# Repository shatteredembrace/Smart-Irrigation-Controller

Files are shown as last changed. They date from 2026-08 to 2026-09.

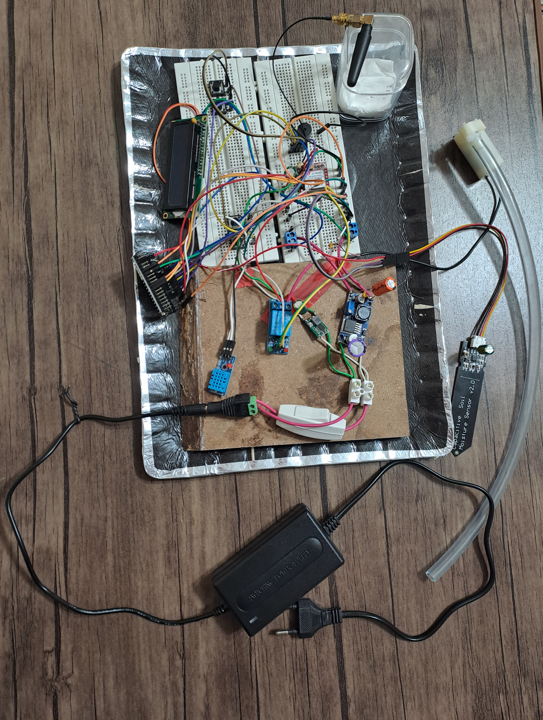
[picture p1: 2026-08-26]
Prototype/img/20260826_171202.jpg

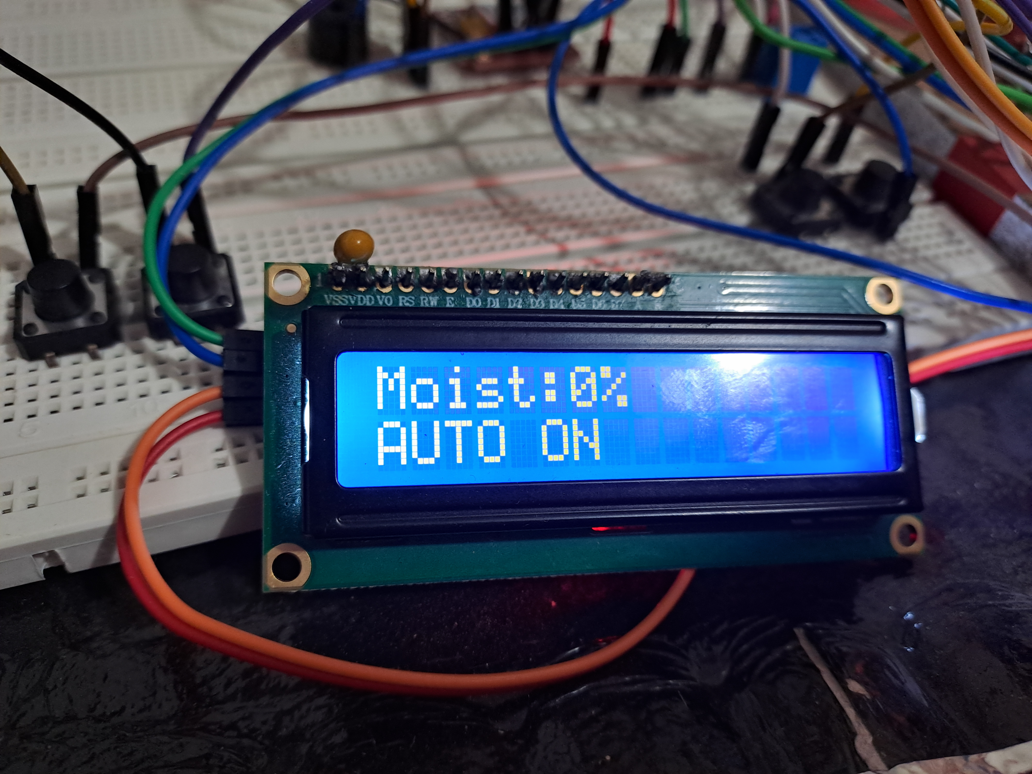
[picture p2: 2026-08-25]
Prototype/img/20260826_011637.jpg

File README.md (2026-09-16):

# Smart Irrigation Controller(Work in progress)

ESP32-based smart irrigation controller with automatic soil-moisture control, GSM communication, Wi-Fi API, environmental monitoring, and safety protection.

> **License:** Proprietary — All Rights Reserved. Contributions are welcome via Pull Requests. See [LICENSE](LICENSE) and [CONTRIBUTING.md](CONTRIBUTING.md) for details.

## Project Status
- [x] KiCad schematic
- [x] ERC verification
- [x] Prototype firmware
- [ ] PCB design
- [ ] PCB fabrication
- [ ] Final hardware testing

## Main Features

- Automatic irrigation based on soil moisture
- Manual pump control
- ESP32 control system
- Soil-moisture sensing
- DHT11 temperature and humidity monitoring
- SIM800L GSM/SMS communication
- Wi-Fi connectivity and HTTP API
- LCD user interface
- Push-button menu system
- EEPROM configuration storage
- Pump runtime protection
- Sensor fault detection
- GSM alert system

## Hardware

The current hardware design includes:

- ESP32 38-pin module
- LM2596 voltage regulator
- Mini360 voltage regulator
- SIM800L
- DHT11
- Soil-moisture sensor
- Relay driver
- 2N2222 transistor
- LCD with I2C interface
- Push buttons
- Buzzer
- 12 V power input
- General-purpose electrolytic capacitors(1000uF)
- Low-ESR capacitors(1000uF)
- Ceramic capacitors(100nF)

## Repository Structure

```

├── README.md
├── LICENSE
├── firmware/
├── hardware/
│   ├── schematic/
│   └── documentation/
├── docs/
│   ├── hardware-design.md
│   ├── firmware-architecture.md
│   ├── troubleshooting.md
│   ├── testing.md
│   └── communication.md
└── prototype/
```

Schematic

The current KiCad schematic represents the electrical architecture of the prototype.

PCB design will be developed in a later revision.

## Future Work :

PCB layout
PCB fabrication
Hardware validation
Final enclosure
Improved power protection
Extended communication features

## Overview

This project is an ESP32-based smart irrigation controller designed to monitor soil moisture and control a water pump according to configurable moisture thresholds. The system supports both automatic and manual operation through a local LCD interface, while also providing remote control and status monitoring through Wi-Fi and GSM/SMS communication.
The controller uses a soil-moisture sensor as the primary input for automatic irrigation, with a DHT sensor providing environmental temperature and humidity data. A relay-driven pump provides the irrigation output, while configurable calibration values and start/stop thresholds allow the system to be adapted to different soil and sensor characteristics.
The hardware was developed and validated initially as a functional prototype. The current repository documents the validated schematic and firmware; PCB design and further hardware refinement are planned as subsequent development stages.

## Features

•	Automatic irrigation based on configurable soil-moisture start and stop thresholds.

•	Manual pump control through the local LCD interface.

•	Soil-moisture calibration using configurable dry and wet reference values.

•	Temperature and humidity monitoring using a DHT sensor.

•	LCD user interface with dashboard, operating-mode selection, manual pump control, and configuration menus.

•	Wi-Fi connectivity for remote status monitoring and authenticated pump/control commands through an HTTP API.

•	GSM/SMS connectivity through the SIM800L module for remote commands and status communication.

•	Relay-based pump control with software handling of the relay's active logic.

•	Pump runtime protection to prevent the pump from operating continuously beyond the configured safety limit.

•	Sensor fault detection with pump shutdown when a critical soil-moisture sensor fault is detected.

•	Persistent configuration for operating mode, moisture thresholds, and calibration parameters.

•	Audible feedback through a buzzer for user-interface actions and system events.

## System Architecture

The system is organized around an ESP32 microcontroller that acts as the central control and communication unit. It acquires sensor data, manages the irrigation state, drives the pump relay, updates the local LCD interface, and handles remote commands received through Wi-Fi and GSM.

Functional Architecture
```

                         ┌─────────────────────┐
                         │       ESP32         │
                         │                     │
                         │  Control Logic      │
                         │  State Management   │
                         │  UI Management      │
                         │  Communications     │
                         └──────────┬──────────┘
                                    │
          ┌─────────────────────────┼─────────────────────────┐
          │                         │                         │
          ▼                         ▼                         ▼
   ┌─────────────┐           ┌─────────────┐           ┌─────────────┐
   │ Soil Sensor │           │ DHT Sensor  │           │ LCD + I²C   │
   │  Moisture   │           │ Temp/Humid. │           │    UI       │
   └─────────────┘           └─────────────┘           └─────────────┘
          │
          │ moisture data
          ▼
   ┌─────────────────────────────────────────────────────────────┐
   │                    Irrigation Control                       │
   │                                                             │
   │   AUTO:   START/STOP thresholds determine pump state        │
   │   MANUAL: User directly controls pump state                 │
   └──────────────────────────────┬──────────────────────────────┘
                                  │
                                  ▼
                           ┌─────────────┐
                           │ Relay Driver│
                           │  2N2222     │
                           └──────┬──────┘
                                  │
                                  ▼
                           ┌─────────────┐
                           │    Relay    │
                           └──────┬──────┘
                                  │
                                  ▼
                              ┌───────┐
                              │ Pump  │
                              └───────┘

        ┌─────────────────┐                 ┌─────────────────┐
        │      Wi-Fi      │                 │     SIM800L     │
        │  HTTP API       │                 │    GSM / SMS    │
        └────────┬────────┘                 └────────┬────────┘
                 │                                   │
                 └────────────────┬──────────────────┘
                                  ▼
                               ESP32
```

The separate regulator paths isolate the high-current GSM load from the main logic supply while maintaining a common electrical reference between the subsystems. The common ground is required for reliable signal communication between the ESP32 and externally powered modules such as the SIM800L.

## Hardware Design

### Main Controller
ESP32 acts as the central controller, handling sensor acquisition,
irrigation control, user interface, and communication.

### Power Supply
The system uses a 12 V input with separate regulated supply paths
for the ESP32/logic and SIM800L. The separate branches reduce the
effect of GSM transient current demand on the main logic supply,
while maintaining a common ground reference.

### Sensors
- Capacitive soil-moisture sensor connected to an ESP32 ADC input.
- DHT sensor for temperature and relative humidity.

### Pump Control
The pump is switched through a relay driven by a 2N2222 transistor,
rather than directly from an ESP32 GPIO.

### User Interface
A 16×2 I²C LCD and physical buttons provide local monitoring,
configuration, and manual pump control.

### Communication
- Wi-Fi through the ESP32's integrated interface and HTTP API.
- GSM/SMS through the SIM800L UART interface.

### Power Integrity
Local decoupling and bulk capacitance are used to support supply
stability and transient load behavior.

## Design Philosophy

The hardware was designed around several principles:

1.	Keep high-current loads away from direct microcontroller GPIO drive.
2.	Provide appropriate regulation for subsystems with different power requirements.
3.	Maintain a common signal reference between communicating subsystems.
4.	Use calibration rather than assuming a universal raw sensor-to-percentage relationship.
5.	Keep the schematic readable through functional grouping and appropriate net labeling.
6.	Treat power integrity and transient behavior as part of the system design rather than as an afterthought.

## Firmware Architecture

The firmware is organized around a non-blocking control loop in which sensor acquisition, user-interface handling, irrigation control, communication, and safety checks are processed as independent tasks.
The ESP32 acts as the central software controller and maintains the current system state, including the operating mode, sensor measurements, pump state, configuration parameters, and communication status.

Main Control Flow
```

                    ┌──────────────────┐
                    │   System Setup   │
                    │                  │
                    │ GPIO / LCD /     │
                    │ Sensors / Wi-Fi  │
                    │ GSM initialization│
                    └────────┬─────────┘
                             │
                             ▼
                    ┌──────────────────┐
                    │    Main Loop     │
                    └────────┬─────────┘
                             │
          ┌──────────────────┼───────────────────┐
          │                  │                   │
          ▼                  ▼                   ▼
   Sensor Processing    User Interface      Communications
          │                  │                   │
          ▼                  ▼                   ▼
   Sensor / Fault       LCD + Buttons       Wi-Fi + GSM
      State                  │                   │
          │                  └────────┬──────────┘
          │                           │
          └──────────────┬────────────┘
                         ▼
                 Irrigation Control
                         │
              ┌──────────┴──────────┐
              │                     │
             AUTO                 MANUAL
              │                     │
        START / STOP            User command
        thresholds                  │
              │                     │
              └──────────┬──────────┘
                         ▼
                    Pump Control
                         │
                         ▼
                       Relay
```

## Operating Modes

The firmware maintains two primary irrigation modes.

AUTO Mode:
In automatic mode, the pump state is determined from the calibrated soil-moisture measurement and the configured START and STOP thresholds.
The use of separate start and stop thresholds provides hysteresis. This prevents the pump from rapidly switching states when the measured moisture is close to a single threshold.
Conceptually:
Moisture < START  → Pump ON
Moisture ≥ STOP   → Pump OFF
The exact boundary behavior is implemented by the firmware.
MANUAL Mode:
In manual mode, the automatic moisture-control decision is disabled and the user directly selects the pump state through the LCD interface.
The manual interface provides explicit PUMP ON and PUMP OFF commands.
This separates user-directed operation from the automatic irrigation algorithm.

## Control Logic

The soil-moisture sensor is sampled through the ESP32 ADC and
converted to a normalized moisture percentage using configurable
DRY and WET calibration references.

All pump-control paths converge on the same control mechanism:

- Automatic moisture control
- LCD manual control
- Wi-Fi commands
- GSM/SMS commands

A configurable pump-runtime timeout provides an additional safeguard
against indefinite pump operation.

## LCD User Interface
```
The LCD interface is implemented as a collection of screens/states rather than as one continuously redrawn menu.
The main interface consists of:
Main Menu
├── AUTO
├── MANUAL
│   ├── PUMP ON
│   └── PUMP OFF
└── SETTINGS
    ├── START
    ├── STOP
    ├── DRY
    └── WET
The settings interface allows the user to modify the automatic irrigation thresholds and sensor calibration parameters.
The display logic also explicitly manages the contents of individual LCD fields so that remnants of previous, longer strings are not left visible after navigation.
```

## Communication Interfaces

### Wi-Fi

The ESP32 exposes an HTTP API for status monitoring and authenticated
control commands.

GET /status

/control?key=<API_KEY>&cmd=<COMMAND>

Supported commands include:

- AUTO
- MANUAL
- PUMP_ON
- PUMP_OFF
- RESET_PUMP

### GSM / SMS

The SIM800L provides an independent remote-control path through SMS.
Received commands are routed through the same command-processing layer
used by the local and Wi-Fi interfaces.

## Configuration and Persistence

User-configurable parameters are stored separately from transient runtime state.
Configuration includes the values required for irrigation thresholds and sensor calibration. 

## Safety and Fault Handling

The firmware includes software-level safeguards intended to prevent
common sensor and control failures from causing uncontrolled pump
operation.

Implemented protections include:

- Critical soil-moisture sensor fault handling
- Maximum continuous pump runtime
- Pump-state validation
- Hysteresis between START and STOP thresholds
- Consistent command routing across local and remote interfaces

The general failure-handling principle is to prevent unreliable
conditions from resulting in indefinite irrigation.

## Troubleshooting & Engineering Validation

Prototype debugging was performed using a measurement-based fault
isolation approach rather than modifying firmware based only on
observed symptoms.

The development process included:

- Schematic inspection
- Continuity and voltage measurements
- Serial diagnostics
- Subsystem isolation
- Controlled functional tests
- KiCad ERC validation

Representative issues included:

- SIM800L UART failure caused by missing common ground between
  independently regulated subsystems.
- Relay/pump logic inversion caused by the relay's active-low interface.
- LCD residual characters caused by rewriting shorter strings over
  longer previous content.
- DHT communication failures investigated independently from other
  subsystems.
- KiCad ERC errors resolved by correcting actual connectivity and
  electrical-type issues rather than broadly suppressing checks.

## Testing & Validation
```

The prototype was tested incrementally, with individual subsystems validated before being tested as an integrated system. Functional tests were performed on the sensor interfaces, user interface, actuator control, Wi-Fi API, and GSM communication.
Functional Test Matrix
Subsystem	Test	Expected Result	Result
ESP32	Power-up and initialization	Controller starts normally	✅
Soil sensor	Change sensor conditions	Moisture reading changes accordingly	✅
DHT sensor	Read temperature and humidity	Valid environmental readings are obtained	✅
LCD	Dashboard display	Current system state is displayed correctly	✅
LCD	Menu navigation	Menus can be navigated using the buttons	✅
LCD	Manual pump control	User can turn the pump ON/OFF	✅
LCD	Configuration	START/STOP and calibration values can be modified	✅
Relay	Pump ON command	Relay switches to the active state	✅
Pump	Manual ON/OFF	Physical pump follows the selected state	✅
AUTO mode	Low moisture condition	Pump activates according to START threshold	✅
AUTO mode	Adequate moisture condition	Pump stops according to STOP threshold	✅
Pump safety	Extended continuous operation	Safety timeout prevents indefinite operation	✅
Wi-Fi	Network connection	ESP32 connects and obtains an IP address	✅
HTTP API	/status	Valid JSON system status is returned	✅
HTTP API	Unauthorized control request	Request is rejected	✅
HTTP API	Authenticated MANUAL command	Command is accepted	✅
HTTP API	Authenticated PUMP_ON	Pump activates	✅
HTTP API	Authenticated PUMP_OFF	Pump stops	✅
SIM800L	AT communication	Modem responds to initialization commands	✅
GSM/SMS	SMS reception	Incoming command is detected and parsed	✅
GSM/SMS	STATUS	Status response is returned by SMS	✅
GSM/SMS	Pump control	SMS command changes pump state	✅
Schematic	KiCad ERC	No unresolved ERC errors remain	✅
```

## Build and Setup

### Hardware

Before powering the prototype, verify:

- Input supply voltage
- Regulated supply voltages
- Common ground connections
- ESP32 GPIO assignments
- Sensor connections
- Relay and pump connections
- SIM800L power and UART connections

Refer to the KiCad schematic and pin-assignment documentation for
the complete electrical connections.

### Firmware

The firmware is developed for the ESP32 using the Arduino framework.

Before compiling, configure the project-specific parameters:

- Wi-Fi credentials
- Wi-Fi API key
- GSM/SIM configuration
- Hardware pin assignments
- Irrigation defaults

Real credentials must never be committed to the public repository.

### Initial Configuration

1. Verify sensor readings.
2. Perform DRY/WET calibration.
3. Configure START/STOP thresholds.
4. Verify manual pump operation.
5. Test AUTO mode.
6. Test Wi-Fi/API control.
7. Test GSM/SMS functionality.
8. Verify pump safety behavior.

## Security

The public repository must not contain real:
•	Wi-Fi passwords;
•	API keys;
•	SIM credentials;
•	telephone numbers;
•	other authentication secrets.
Example placeholders should be used instead:
WIFI_SSID     = "YOUR_WIFI_SSID"
WIFI_PASSWORD = "YOUR_WIFI_PASSWORD"
WIFI_API_KEY  = "YOUR_API_KEY"
The API key should be treated as a credential even though the project is intended as a prototype.

## User Guide

For detailed operating instructions, see
[User Guide](docs/user-guide.md).

##Security Considerations

The Wi-Fi control endpoint is protected by an API key.
The API key must be treated as a credential and must not be committed to the public repository.

## Future Work

### PCB Development

Replace prototype wiring with a dedicated PCB featuring controlled
routing, dedicated connectors, improved power distribution, and
better mechanical integration.

### Power Integrity

Further validate supply stability during worst-case GSM transmission
bursts and simultaneous pump operation.

### Electrical Protection

Add production-oriented protection such as:

- Overvoltage protection
- Reverse-polarity protection
- Fusing
- Transient suppression
- Improved actuator isolation
- Hardware-level pump shutdown

### Environmental & Mechanical Design

Develop a suitable enclosure with appropriate ingress protection,
connector protection, cable strain relief, thermal management,
mounting, and serviceability.

### Sensor Calibration

Improve the calibration workflow and evaluate long-term effects of
sensor aging, soil composition, environmental conditions, and
installation depth.

### Communication Security

Replace the prototype-oriented API-key security model with stronger
authentication, encrypted transport, credential management, and
network isolation where required.

### Reliability Testing

Perform long-duration testing, repeated switching, power-cycle tests,
sensor-disconnection tests, communication-loss tests, and
brownout/transient-condition testing.

### Firmware

Potential improvements include OTA updates, enhanced diagnostics,
event logging, fault recovery, and expanded configuration management.

## Current Scope
```
The current project should therefore be considered a functional embedded-systems prototype, rather than a finished commercial irrigation product.
The current revision demonstrates the integration of:
Sensors
   ↓
ESP32 control system
   ↓
Local user interface
   ↓
Automatic / manual control
   ↓
Relay / pump actuator

          +
Wi-Fi remote control
          +
GSM / SMS communication
          +
```

Software safety mechanisms

PCB development, production-level protection, environmental packaging, extensive reliability testing, and production-grade communication security constitute subsequent engineering stages.

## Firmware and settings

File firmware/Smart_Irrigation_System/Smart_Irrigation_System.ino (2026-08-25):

#include <EEPROM.h>
#include <Wire.h>
#include <LiquidCrystal_I2C.h>
#include <DHT.h>
#include <HardwareSerial.h>
#include <WiFi.h>
#include <WebServer.h>
#include <esp_task_wdt.h>

LiquidCrystal_I2C lcd(0x27, 16, 2);

// ==========================================
// 1 & 2: Constexpr Definitions (Modern C++)
// ==========================================
constexpr uint16_t EEPROM_SIZE = 128;
constexpr uint16_t SETTINGS_ADDR = 0;

constexpr uint16_t EEPROM_MAGIC_VAL = 0xA55A;
constexpr uint8_t  EEPROM_VERSION_VAL = 1;

constexpr uint8_t SOIL_PIN   = 34;
constexpr uint8_t RELAY_PIN  = 27;
constexpr uint8_t UP_BTN     = 32;
constexpr uint8_t DOWN_BTN   = 33;
constexpr uint8_t ENTER_BTN  = 25;
constexpr uint8_t BACK_BTN   = 26;
constexpr uint8_t BUZZER_PIN = 14;

// DHT Settings
constexpr uint8_t DHT_PIN = 13;
constexpr uint8_t DHT_TYPE = DHT11;

// SIM800L Settings
constexpr char ALERT_PHONE[] = "+XXXXXXXXXX";
constexpr uint8_t AUTHORIZED_NUMBERS = 2; //it can be more

const char* authorizedNumbers[AUTHORIZED_NUMBERS] =
{
  "+xxxxxxxxxxxx",
  "+yyyyyyyyyyyy"
};

constexpr uint8_t SIM800_RX_PIN = 16;
constexpr uint8_t SIM800_TX_PIN = 17;
constexpr uint32_t SIM800_BAUD = 9600;

// Wi-Fi Settings
constexpr char WIFI_SSID[] = "YOUR WIFI_NAME";
constexpr char WIFI_PASSWORD[] = "YOUR PASSWORD";
constexpr char WIFI_API_KEY[] = "YOUR API_KEY";


constexpr bool RELAY_ON  = LOW;
constexpr bool RELAY_OFF = HIGH;

// Menu Bounds
constexpr uint8_t MAIN_MENU_ITEMS = 3;
constexpr uint8_t SETTINGS_MENU_ITEMS = 4;

// Default Configuration Values
constexpr uint8_t DEFAULT_START = 35;
constexpr uint8_t DEFAULT_STOP  = 60;
constexpr uint16_t DEFAULT_DRY  = 2800;
constexpr uint16_t DEFAULT_WET  = 1800;

// ==========================================
// 3: System Constants
// ==========================================
constexpr uint32_t GSM_INIT_RETRY_DELAY = 3000;
constexpr uint32_t WDT_TIMEOUT_SECONDS = 30;
constexpr uint32_t EEPROM_RETRY_DELAY = 1000;
constexpr uint8_t EEPROM_MAX_RETRIES = 3;
constexpr uint32_t PUMP_FAULT_RESET_HOLD = 3000;
constexpr const char* CMD_RESET_PUMP = "RESET PUMP";
constexpr uint16_t CAL_MIN_DIFF = 300;
constexpr uint8_t DHT_FAIL_LIMIT = 3;
constexpr uint8_t DHT_RECOVERY_LIMIT = 2;
constexpr uint8_t SENSOR_BAD_SAMPLE_LIMIT = 5;
constexpr uint8_t SENSOR_GOOD_SAMPLE_LIMIT = 10;
constexpr uint8_t ALERT_QUEUE_SIZE = 8;
constexpr uint8_t ALERT_MESSAGE_SIZE = 96;

constexpr uint32_t GSM_NETWORK_CHECK_INTERVAL = 10000;
constexpr uint32_t GSM_SIGNAL_CHECK_INTERVAL  = 30000;
constexpr uint32_t GSM_RECOVERY_DELAY         = 30000;

constexpr uint8_t GSM_MAX_NETWORK_FAILURES = 3;
constexpr uint8_t GSM_MAX_MODEM_FAILURES   = 3;
constexpr uint32_t LCD_REFRESH_TIME    = 250;
constexpr uint32_t SERIAL_REFRESH_TIME = 1000;
constexpr uint32_t BUTTON_DEBOUNCE     = 50; 
constexpr uint32_t EEPROM_COMMIT_DELAY = 5000;
constexpr uint32_t MAX_PUMP_RUNTIME    = 900000; // 15 Minutes
constexpr uint32_t DHT_INTERVAL        = 2000; 

// ==========================================
// Hardware Objects
// ==========================================
DHT dht(DHT_PIN, DHT_TYPE);
HardwareSerial sim800(2);

// ==========================================
// 4: Enum Classes
// ==========================================
enum class Mode : uint8_t
{
  AUTO,
  MANUAL
};

enum class Screen : uint8_t
{
  DASHBOARD,
  MAIN_MENU,
  SETTINGS_MENU,
  MANUAL_MENU,
  EDIT_START,
  EDIT_STOP,
  EDIT_DRY,
  EDIT_WET
};

// ==========================================
// 5 & 6: Struct & Memory Layout Validation
// ==========================================
struct DeviceSettings
{
  uint16_t magic;
  uint8_t  version;
  Mode     mode;
  uint8_t  startMoisture;
  uint8_t  stopMoisture;
  uint16_t dryValue;
  uint16_t wetValue;
};

static_assert(sizeof(DeviceSettings) <= 16, "DeviceSettings grew unexpectedly.");

DeviceSettings settings;

// Forward Declarations
void changeMode(Mode mode);
int getMoisture();

bool isCalibrationValid(
  uint16_t dryValue,
  uint16_t wetValue
);

// ==========================================
// 7: Hardware Abstraction (Input & Sensors)
// ==========================================
struct Button {
  uint8_t pin;
  bool state = HIGH;
  bool lastFlicker = HIGH;
  bool lastState = HIGH;
  unsigned long lastDebounceTime = 0;

  void init(uint8_t p) {
    pin = p;
    pinMode(pin, INPUT_PULLUP);
  }

  void update() {
    lastState = state; 
    bool reading = digitalRead(pin);

    if (reading != lastFlicker) {
      lastDebounceTime = millis();
    }

    if ((millis() - lastDebounceTime) > BUTTON_DEBOUNCE) {
      if (reading != state) {
        state = reading;
      }
    }
    lastFlicker = reading;
  }

  bool isPressed() const {
    return (lastState == HIGH && state == LOW);
  }
};

Button btnUp, btnDown, btnEnter, btnBack;

struct DHTData
{
  float temperature = 0.0f;
  float humidity = 0.0f;

  bool valid = false;

  uint8_t failCount = 0;
  uint8_t successCount = 0;

  unsigned long lastRead = 0;
};

DHTData dhtData;

// ==========================================
// 8: Error Manager
// ==========================================
struct ErrorManager
{
  bool sensorFault = false;
  bool pumpTimeout = false;
  bool calibrationError = false;
  bool eepromError = false;

  uint8_t sensorBadSamples = 0;
  uint8_t sensorGoodSamples = 0;
};
ErrorManager systemError;

// ==========================================
// Communication Subsystems (GSM & Wi-Fi)
// ==========================================
struct GSMManager
{
  bool initialized = false;
  bool networkRegistered = false;
  bool smsReady = false;

  int signalStrength = -1;

  uint8_t networkFailCount = 0;
  uint8_t modemFailCount = 0;

  unsigned long lastNetworkCheck = 0;
  unsigned long lastSignalCheck = 0;
  unsigned long lastRecoveryAttempt = 0;

  bool pumpTimeoutAlertSent = false;
  bool sensorFaultAlertSent = false;
};

GSMManager gsm;

enum class GSMState : uint8_t
{
  OFFLINE,
  INITIALIZING,
  ONLINE,
  DEGRADED,
  RECOVERING
};

enum class GSMInitStep : uint8_t
{
  NONE,
  AT,
  ECHO_OFF,
  SIM_CHECK,
  SMS_MODE,
  CHARSET,
  SMS_NOTIFICATION,
  COMPLETE,
  FAILED
};

enum class CommandType : uint8_t
{
  NONE,
  PUMP_ON,
  PUMP_OFF,
  MODE_AUTO,
  MODE_MANUAL,
  RESET_PUMP_FAULT,
  GET_STATUS
};
enum class CommandResult : uint8_t
{
  SUCCESS,
  REJECTED,
  INVALID,
  SAFETY_LOCKED
};

CommandResult executeCommand(CommandType command);
GSMInitStep gsmInitStep = GSMInitStep::NONE;



enum class GSMOperation : uint8_t
{
  NONE,
  NETWORK_CHECK,
  SIGNAL_CHECK
};

GSMState gsmState = GSMState::OFFLINE;
GSMOperation gsmOperation = GSMOperation::NONE;

struct GSMTransaction
{
  bool active = false;

  String command;
  String expected;

  String response;

  unsigned long startTime = 0;
  uint32_t timeout = 0;
};

GSMTransaction gsmTransaction;

bool startGSMCommand(
  const char* command,
  const char* expected,
  uint32_t timeout
)
{
  if (gsmTransaction.active)
    return false;

  gsmTransaction.command = command;
  gsmTransaction.expected = expected;
  gsmTransaction.response = "";
  gsmTransaction.timeout = timeout;
  gsmTransaction.startTime = millis();
  gsmTransaction.active = true;

  sim800.println(command);

  return true;
}


struct SMSTransaction
{
  bool pending = false;
  bool waitingForPrompt = false;
  bool waitingForResult = false;
  bool isAlert = false;
  String phoneNumber;
  String message;
  String response;

  unsigned long startTime = 0;
};

SMSTransaction smsTransaction;

bool startSMS(
  const char* phoneNumber,
  const char* message,
  bool alertMessage = false
);

struct AlertQueue
{
  char messages[ALERT_QUEUE_SIZE][ALERT_MESSAGE_SIZE];

  uint8_t head = 0;
  uint8_t tail = 0;
  uint8_t count = 0;
};

// ==========================================
// Single Source of Truth Definitions
// ==========================================
struct SystemState
{
  bool pumpState = false;
  bool previousPumpState = false;
  bool manualPumpState = false;

  unsigned long pumpStartTime = 0;

  float filteredADC = 0;
};

struct UIState
{
  Screen currentScreen = Screen::DASHBOARD;
  Screen previousScreen = Screen::DASHBOARD;
  bool lcdNeedsRefresh = true;

  int menuIndex = 0;
  int settingsIndex = 0;
  int editValue = 0;
};

SystemState sys;
UIState ui;


AlertQueue alertQueue;

// GSM SMS Receiver Variables
String gsmRxBuffer = "";
String incomingSMSNumber = "";
String incomingSMSMessage = "";
bool smsReceiving = false;

void processGSM();
void processGSMRx();
void processGSMTransaction();
void processSMSTransaction();
void processGSMInitialization();


bool startSMS(
  const char* phoneNumber,
  const char* message,
  bool alertMessage
)
{
  if (smsTransaction.pending)
    return false;

  if (!gsm.initialized ||
      !gsm.networkRegistered)
    return false;

  smsTransaction.phoneNumber = phoneNumber;
  smsTransaction.message = message;
  smsTransaction.response = "";

  smsTransaction.pending = true;
  smsTransaction.waitingForPrompt = false;
  smsTransaction.waitingForResult = false;
  smsTransaction.isAlert = alertMessage;
  smsTransaction.startTime = millis();

  return true;
}

bool isAuthorizedNumber(const String& sender);
void processSMS(const String& sender, const String& message);
void sendStatusSMS(const char* phoneNumber);

void sendGSMAlert(const char* message);
void processGSMAlerts();
void processAlertQueue();

struct WiFiManager
{
  bool connected = false;
  bool apiStarted = false;
  unsigned long lastAttempt = 0;
};

WiFiManager wifi;
WebServer server(80);

bool isAuthorizedAPI()
{
  if (!server.hasArg("key"))
    return false;

  return server.arg("key") == WIFI_API_KEY;
}

void handleStatus()
{
  if (!isAuthorizedAPI())
  {
    server.send(
      401,
      "application/json",
      "{\"error\":\"unauthorized\"}"
    );
    return;
  }

  String json = "{";

  json += "\"moisture\":";
  json += getMoisture();

  json += ",\"temperature\":";
  json += dhtData.valid
    ? String(dhtData.temperature, 1)
    : "null";

  json += ",\"humidity\":";
  json += dhtData.valid
    ? String(dhtData.humidity, 1)
    : "null";

  json += ",\"pump\":";
  json += sys.pumpState ? "true" : "false";

  json += ",\"mode\":\"";
  json += settings.mode == Mode::AUTO
    ? "AUTO"
    : "MANUAL";
  json += "\"";

  json += ",\"sensorFault\":";
  json += systemError.sensorFault ? "true" : "false";

  json += ",\"pumpTimeout\":";
  json += systemError.pumpTimeout ? "true" : "false";

  json += ",\"gsm\":";
  json += gsm.networkRegistered ? "true" : "false";

  json += "}";

  server.send(
    200,
    "application/json",
    json
  );
}

void handleControl()
{
  if (!isAuthorizedAPI())
  {
    server.send(
      401,
      "application/json",
      "{\"error\":\"unauthorized\"}"
    );
    return;
  }

  if (!server.hasArg("cmd"))
  {
    server.send(
      400,
      "application/json",
      "{\"error\":\"missing cmd\"}"
    );
    return;
  }

  String command = server.arg("cmd");
  command.toUpperCase();

  CommandType type = CommandType::NONE;

  if (command == "PUMP_ON")
    type = CommandType::PUMP_ON;
  else if (command == "PUMP_OFF")
    type = CommandType::PUMP_OFF;
  else if (command == "AUTO")
    type = CommandType::MODE_AUTO;
  else if (command == "MANUAL")
    type = CommandType::MODE_MANUAL;
  else if (command == "RESET_PUMP")
    type = CommandType::RESET_PUMP_FAULT;
  else
  {
    server.send(
      400,
      "application/json",
      "{\"error\":\"unknown command\"}"
    );
    return;
  }

  CommandResult result = executeCommand(type);

  switch (result)
  {
    case CommandResult::SUCCESS:
      server.send(
        200,
        "application/json",
        "{\"result\":\"accepted\"}"
      );
      break;

    case CommandResult::REJECTED:
      server.send(
        409,
        "application/json",
        "{\"result\":\"rejected\"}"
      );
      break;

    case CommandResult::SAFETY_LOCKED:
      server.send(
        423,
        "application/json",
        "{\"result\":\"safety_locked\"}"
      );
      break;

    case CommandResult::INVALID:
    default:
      server.send(
        400,
        "application/json",
        "{\"result\":\"invalid\"}"
      );
      break;
  }
}
void initializeWiFiAPI()
{
  server.on(
    "/status",
    HTTP_GET,
    handleStatus
  );

  server.on(
    "/control",
    HTTP_GET,
    handleControl
  );

  server.begin();

  Serial.println(
    F("[WIFI] HTTP API started.")
  );
}


// ==========================================
// GSM Subsystem Functions
// ==========================================


void initializeGSM()
{
  if (gsmState == GSMState::INITIALIZING)
    return;

  Serial.println(F("[GSM] Starting initialization state machine."));

  gsmState = GSMState::INITIALIZING;
  gsmInitStep = GSMInitStep::AT;

  gsm.initialized = false;
  gsm.networkRegistered = false;
  gsm.smsReady = false;
  gsm.modemFailCount = 0;

  gsmTransaction.active = false;
  gsmTransaction.response = "";
  gsmOperation = GSMOperation::NONE;

  gsmInitStep = GSMInitStep::AT;

  startGSMCommand(
    "AT",
    "OK",
    3000
  );
}




void updateGSM()
{
  if (gsmState == GSMState::INITIALIZING)
    return;

  if (gsmState == GSMState::OFFLINE)
  {
    static unsigned long lastInitAttempt = 0;

    if (millis() - lastInitAttempt >= GSM_INIT_RETRY_DELAY)
    {
      lastInitAttempt = millis();

      Serial.println(
        F("[GSM] Retrying initialization...")
      );

      initializeGSM();
    }

    return;
  }

  if (gsmState != GSMState::ONLINE &&
      gsmState != GSMState::DEGRADED)
  {
    return;
  }

  if (gsmTransaction.active ||
      smsTransaction.pending)
  {
    return;
  }

  // Network check
  if (
    millis() - gsm.lastNetworkCheck >=
    GSM_NETWORK_CHECK_INTERVAL
  )
  {
    gsm.lastNetworkCheck = millis();

    gsmOperation =
      GSMOperation::NETWORK_CHECK;

    startGSMCommand(
      "AT+CREG?",
      "OK",
      3000
    );

    return;
  }

  // Signal check
  if (
    millis() - gsm.lastSignalCheck >=
    GSM_SIGNAL_CHECK_INTERVAL
  )
  {
    gsm.lastSignalCheck = millis();

    gsmOperation =
      GSMOperation::SIGNAL_CHECK;

    startGSMCommand(
      "AT+CSQ",
      "OK",
      2000
    );
  }
}



// ==========================================
// GSM SMS Processing Logic
// ==========================================
void processGSMRx()
{
  while (sim800.available())
  {
    char c = sim800.read();

    // =====================================================
    // 1. SMS SEND: WAITING FOR '>' PROMPT
    // =====================================================
    if (smsTransaction.waitingForPrompt)
    {
      if (c == '>')
      {
        sim800.print(smsTransaction.message);
        sim800.write(26); // CTRL+Z

        smsTransaction.waitingForPrompt = false;
        smsTransaction.waitingForResult = true;
        smsTransaction.startTime = millis();
        smsTransaction.response = "";
      }

      continue;
    }

    // =====================================================
    // 2. SMS SEND: WAITING FOR FINAL RESULT
    // =====================================================
    if (smsTransaction.waitingForResult)
    {
      smsTransaction.response += c;

      if (smsTransaction.response.indexOf("OK") >= 0)
      {
        Serial.println(F("[GSM] SMS sent."));

        if (smsTransaction.isAlert)
        {
          if (alertQueue.count > 0)
          {
            alertQueue.head =
              (alertQueue.head + 1) % ALERT_QUEUE_SIZE;

            alertQueue.count--;

            Serial.println(
              F("[ALERT] Queue item delivered.")
            );
          }
        }

        smsTransaction.pending = false;
        smsTransaction.waitingForPrompt = false;
        smsTransaction.waitingForResult = false;
        smsTransaction.isAlert = false;
        smsTransaction.response = "";
      }
      else if (
        smsTransaction.response.indexOf("ERROR") >= 0
      )
      {
        Serial.println(F("[GSM] SMS failed."));

        // Keep alert in queue on failure.
        smsTransaction.pending = false;
        smsTransaction.waitingForPrompt = false;
        smsTransaction.waitingForResult = false;
        smsTransaction.isAlert = false;
        smsTransaction.response = "";
      }

      continue;
    }

    // =====================================================
    // 3. NORMAL GSM / AT RESPONSE
    // =====================================================
    if (gsmTransaction.active)
    {
      gsmTransaction.response += c;
      continue;
    }

    // =====================================================
    // 4. UNSOLICITED GSM DATA / INCOMING SMS
    // =====================================================
    gsmRxBuffer += c;

    if (gsmRxBuffer.length() > 512)
    {
      gsmRxBuffer = "";
      smsReceiving = false;
    }

    // -----------------------------------------
    // Find incoming SMS header
    // -----------------------------------------
    if (!smsReceiving)
    {
      int headerIndex =
        gsmRxBuffer.indexOf("+CMT:");

      if (headerIndex >= 0)
      {
        int lineEnd =
          gsmRxBuffer.indexOf('\n', headerIndex);

        if (lineEnd >= 0)
        {
          String header =
            gsmRxBuffer.substring(
              headerIndex,
              lineEnd
            );

          int q1 = header.indexOf('"');
          int q2 = header.indexOf('"', q1 + 1);

          if (q1 >= 0 && q2 > q1)
          {
            incomingSMSNumber =
              header.substring(q1 + 1, q2);

            smsReceiving = true;

            gsmRxBuffer =
              gsmRxBuffer.substring(lineEnd + 1);
          }
        }
      }
    }

    // -----------------------------------------
    // Read SMS body
    // -----------------------------------------
    if (smsReceiving)
    {
      int lineEnd =
        gsmRxBuffer.indexOf('\n');

      if (lineEnd >= 0)
      {
        incomingSMSMessage =
          gsmRxBuffer.substring(0, lineEnd);

        incomingSMSMessage.trim();

        processSMS(
          incomingSMSNumber,
          incomingSMSMessage
        );

        incomingSMSNumber = "";
        incomingSMSMessage = "";

        gsmRxBuffer =
          gsmRxBuffer.substring(lineEnd + 1);

        smsReceiving = false;
      }
    }
  }
}
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
void loop()
{
  esp_task_wdt_reset();

  readButtons();
  runCurrentScreen();

  readSensors();
  readDHT();

  processGSM();
  updateGSM();

  updateWiFi();
  server.handleClient();

  controlPump();

  processPumpEvents();
  processGSMAlerts();
  processAlertQueue();

  updateDisplay();
  handleEEPROM();
  updateBuzzer();
  printSerial();
}

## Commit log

2026-08-22 Initial KiCad schematic
    [Smart-Irrigation-Controller.kicad_sch]
2026-08-22 Fix some values in schematic
    [Smart-Irrigation-Controller.kicad_sch]
2026-08-22 Updating/correcting values
    [Smart-Irrigation-Controller.kicad_sch]
2026-08-22 Added a ceramic capacitor between VDD and VSS on LCD module
    For better potential noise reduction
    [Smart-Irrigation-Controller.kicad_sch]
2026-08-25 Common GND, pin change & prototype photos
    Fixed the missed grounding connectivity regarding sim800l and esp32 by making their ground common. Next, changed DHT_pin from 4 to 13. Also, added a couple of prototype photos as "Initial Hardware Prototype".
    [Smart-Irrigation-Controller.kicad_sch]
2026-08-25 New prototype photo(LCD on)
2026-08-26 Updated the missed capacitor near sim800l
2026-08-26 Emphasized "Work in progress" & add capacitors as hardware
2026-08-28 clean up project structure
    - Centralized libraries in libs/ folder
    - Fixed library paths using ${KIPRJMOD}
    [Smart-Irrigation-Controller.kicad_sch]
2026-08-29 Reorganized for better reading
    [Smart-Irrigation-Controller.kicad_sch]
